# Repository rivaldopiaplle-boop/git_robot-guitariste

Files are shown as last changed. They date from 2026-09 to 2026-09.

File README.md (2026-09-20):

# Robot guitariste



Portfolio : https://git-portfolio-rivaldo.vercel.app/projets/robot-guitariste

Projet pluridisciplinaire d'équipe (ENIB, 4ᵉ année) : un robot qui se place sur les frettes d'une guitare et attaque la corde en rythme.

**Ma part** : modélisation des mécanismes et des chaînes cinématiques, outils de simulation en Python (trajectoires, vitesses, accélérations), analyse et optimisation des configurations, intégration mécanique / électronique / logiciel, documentation technique.

## Ce que contient le dossier

```
robot-guitariste/
├── firmware/
│   ├── control_guitarra/          micrologiciel STM32F411 (STM32CubeIDE), version de référence
│   └── versions-precedentes/      control_guitarra1, control_guitarra2
├── simulation/
│   ├── animation_cinematique.py   la cinématique du bras : modèle, trajectoires, animation
│   ├── produire-figures.py        rejoue la simulation et écrit les images, sans fenêtre
│   ├── sorties/                   les images produites, celles que montre le portfolio
│   └── essais/                    les scripts d'essai successifs, gardés pour mémoire
├── analyse-geste/
│   ├── analyser-kinovea.py        relit le relevé Kinovea et en tire les chiffres
│   └── sorties/                   le geste mesuré, sa vitesse, et mesures.json
├── cao-solidworks/                pièces, assemblages et animations SolidWorks
│   └── rendus/                    les animations converties, lisibles partout
├── documents/                     rapport signé, comptes rendus, planification, relevé Kinovea
│                                  (le logiciel Kinovea lui-même reste hors du dépôt)
└── archives/                      export d'origine du projet
```

## Le geste humain, mesuré avant d'être imité

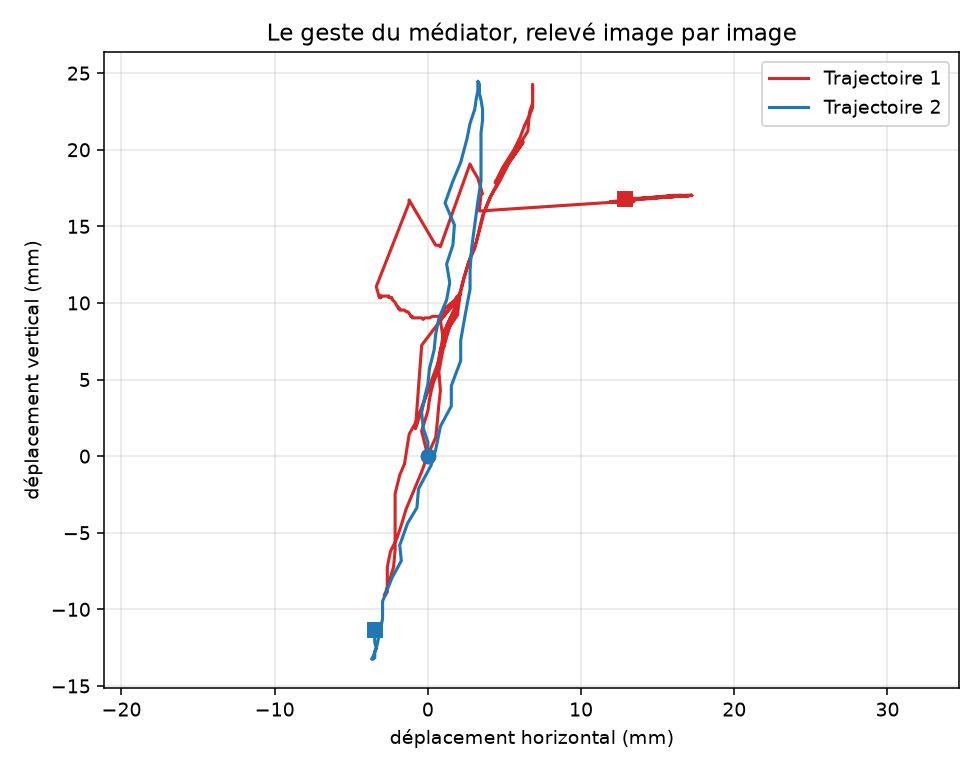
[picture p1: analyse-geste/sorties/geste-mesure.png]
Le geste du médiator relevé image par image


On ne dimensionne pas un robot guitariste sur une intuition. Le geste a d'abord été filmé
au ralenti, à cinquante images par seconde, puis suivi point par point dans Kinovea avec un
étalonnage pris sur l'écart entre deux cordes, onze millimètres. `analyse-geste/` relit ce
relevé et en tire les chiffres qui contraignent le mécanisme :

| Mesure | Valeur |
|---|---|
| Points suivis | 272 sur 5.42 s |
| Amplitude du balayage | 33.3 mm, soit environ trois cordes |
| Chemin parcouru par le médiator | 185.7 mm |
| Vitesse maximale | 465 mm/s |
| Vitesse moyenne | 34 mm/s |

C'est la cible. Les courbes de la simulation, plus bas, disent ce que le mécanisme sait
faire ; l'écart entre les deux est ce qui a guidé les choix de conception.

```bash
cd analyse-geste && python analyser-kinovea.py
```

## La simulation cinématique

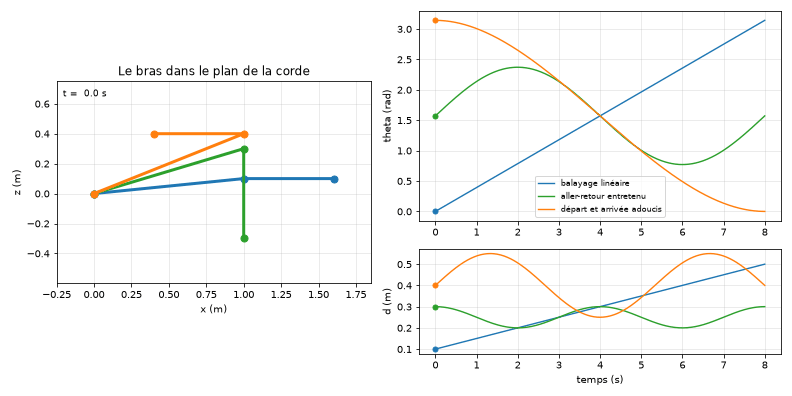
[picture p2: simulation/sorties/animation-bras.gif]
Le bras en mouvement


Le mécanisme compte deux axes : une articulation prismatique qui porte le bras le long de
la corde, et une articulation rotoïde qui présente l'outil sur la frette. La position de
l'outil se calcule directement, `x = A + B cos(theta)` et `z = d - B sin(theta)`, ce qui
permet d'éprouver un mouvement avant de l'usiner.

Trois mouvements sont éprouvés : un balayage linéaire, un aller-retour entretenu, et un
déplacement adouci au départ et à l'arrivée. Les courbes de vitesse et d'accélération
disent lequel le mécanisme peut suivre :

| Mouvement | Vitesse maximale | Accélération maximale |
|---|---|---|
| Balayage linéaire | 0,39 rad/s | 0 rad/s² (vitesse constante) |
| Aller-retour entretenu | 0,63 rad/s | 0,49 rad/s² |
| Départ et arrivée adoucis | 0,59 rad/s | 0,29 rad/s² |

Le troisième est le bon compromis : presque aussi rapide que l'aller-retour entretenu, avec
une accélération réduite de moitié, donc moins d'effort demandé au moteur et moins de
vibration transmise au manche.

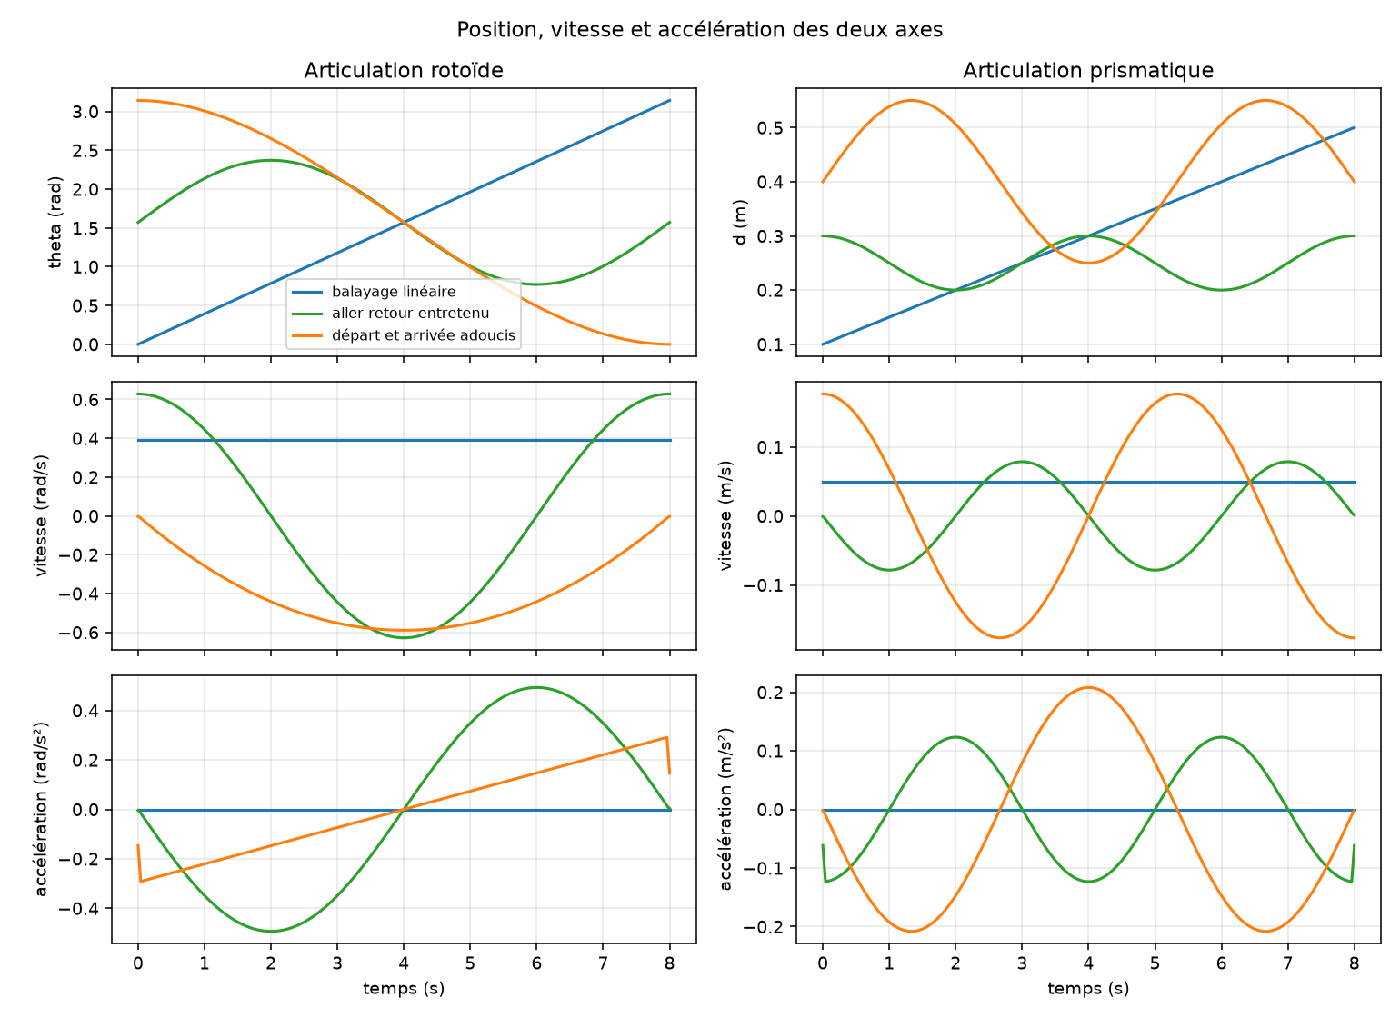
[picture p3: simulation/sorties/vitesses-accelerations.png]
Position, vitesse et accélération


## Reprendre le projet

| Partie | Outil | Démarrer |
|---|---|---|
| Micrologiciel | STM32CubeIDE, carte Nucleo STM32F411 | *File → Import → Existing Projects* → `firmware/control_guitarra`, puis *Build* et *Debug* |
| Interface de pilotage | Python 3 + `pyserial` | `python firmware/control_guitarra/hmi_guitarra.py` (port série de la carte) |
| Simulation | Python 3 + `numpy`, `matplotlib`, `pillow` | `cd simulation && python produire-figures.py` |
| Mécanique | SolidWorks | ouvrir `cao-solidworks/Assemblage1.SLDASM` |

Les vidéos (`documents/*.mp4`) restent sur la machine : elles dépassent la taille acceptée par GitHub.

## État

Terminé dans le cadre du projet d'école. Présenté dans le portfolio (fiche « Robot guitariste »).

## À améliorer

- [ ] Nettoyer `firmware/` : ne garder qu'une version, documenter les commandes série (codes `X1…X12`, états `EN`, `N`, `G`…)
- [ ] `requirements.txt` pour la simulation et l'interface
- [ ] Une vidéo courte du robot qui joue, hébergée hors du dépôt
- [ ] Schéma du câblage (moteur pas-à-pas, solénoïde, alimentation)

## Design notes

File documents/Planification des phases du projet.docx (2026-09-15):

Planification des phases du projet

Phase | Jour N° Semaine | Objectif Semaine | Lundi | Mardi | Mercredi | Jeudi | Vendredi | Samedi | Dimanche
Analyse & Préparation | 37 | - Tâches principales - Travail parallèle (multi-tâches) - Livrables / Objectifs | - Réunion de lancement avec encadrants (clarification objectifs, contraintes). - Étude du dispositif existant (robot-guitare précédent). - État de l’art : dispositifs d’excitation de corde (robots, médiators, autres systèmes). - Comparaison des approches mécaniques et robotiques. - Début de la recherche bibliographique sur les mouvements réels des guitaristes. - Classement des sources et articles scientifiques/vidéos. - Réorientation et clarification du travail à faire et Tableau comparatif des solutions existantes.
| 38 | | - Revue du cahier des charges. - Analyse des mouvements typiques d’un guitariste (angle, vitesse, flexibilité du médiator). - Définir les exigences dynamiques (trajectoire, force, fréquence). - Début modélisation cinématique d’un schéma simple (bras sériel ou parallèle 2 ddl). - Rapport État de l’art + analyse mouvements guitaristes
Modélisation & Dimensionnement | 39
| 40 | - Modélisation cinématique complète (bras sériel et parallèle, comparaison). - Simulation sous MATLAB/Simulink ou Python. - Étude des contraintes mécaniques (forces sur la corde, rigidité médiator). - Choix de l’architecture retenue (sériel ou parallèle).
Conception & Simulation | 41 | - Dimensionnement préliminaire (longueurs des bras, angles de travail, plage de mouvement). - Définir le nombre exact d’actionneurs et leurs caractéristiques. - Recherche de catalogues moteurs/servo + estimation coûts. - Schéma cinématique validé.
| 42 | - - Étude dynamique (vitesses, accélérations, couple moteur nécessaire). - Calculs de puissance et choix moteurs/servo. - En parallèle : début conception CAO (SolidWorks, CATIA, Fusion 360). - Fiche de choix des actionneurs.
Réalisation & Intégration partielle | 43 | - Conception CAO du dispositif (mécanisme complet avec médiator). - Vérification interférences, amplitude des mouvements. Préparation du plan de câblage électronique et schéma de commande. Maquette numérique CAO.
| 44 | - Validation CAO par simulation (trajectoire suivie, faisabilité). - Optimisation (ajustement longueurs, angles). Commande des composants mécaniques/électroniques nécessaires. Rapport conception + liste des pièces (BOM).
| 45 | - Réalisation prototype mécanique (impression 3D, découpe laser, assemblage). - Intégration médiator. Début programmation commande moteurs (Arduino, STM32, etc.). Prototype mécanique brut.
| 46 | - Intégration actionneurs (servo, moteurs). - Tests mécaniques sans guitare (trajectoire seule). Ajustement électronique (capteurs fin de course, réglages). Dispositif fonctionnel (phase 1).
| 47 | - Validation sur guitare (premiers tests de grattage). - Analyse du son produit (qualité excitation). Optimisation des paramètres (vitesse, trajectoire). Rapport tests intermédiaires.
| 48 | - Correction défauts (blocage, rigidité médiator). - Optimisation mécanique (renforts, flexibilité médiator). Rédaction rapport final (début). Version presque finale du dispositif.
Validation finale & Restitution | 49
| 50 | - Intégration finale au robot-guitare existant. - Tests complets sur mélodies programmées. - Présentation aux encadrants. Finalisation du rapport + diaporama soutenance. Rapport complet + démonstration finale
| 51

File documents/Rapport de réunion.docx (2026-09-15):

Rapport de réunion

Réalisation d’une trajectoire complexe pour médiator de robot-guitare

Date : Vendredi 12 septembre 2025, 14h00
Lieu : ENIB

Encadreurs :

M. Guillaume Helbert M. Olivier Chocron

# 1 Contexte du projet

Le projet s’inscrit dans la continuité d’un précédent PPE ayant conduit à la conception d’un premier prototype de robot-guitare capable de jouer une mélodie préprogrammée.
Le dispositif actuel utilise un médiator fixé à l’arbre d’un servo-moteur. Toutefois, la trajectoire simple et la rigidité du médiator entraînent plusieurs limitations :

- Risque de blocage mécanique,
- Dégradation de la qualité sonore,
- Réglage délicat de la position du médiator.

L’objectif de ce nouveau projet est de développer un dispositif plus performant permettant d’obtenir une trajectoire sophistiquée et fluide tout en limitant la complexité du robot-guitare. L’étude porte sur la conception et la modélisation d’un mécanisme sériel ou parallèle comportant au maximum deux actionneurs.

# 2 Ordre du jour de la réunion

- Réorientation du travail à réaliser,
- Présentation par les étudiants de leurs recherches,
- Discussion des solutions possibles pour l’excitation des cordes,
- Définition des tâches techniques à réaliser pour la prochaine échéance.

# 3 Travaux présentés par les étudiants

Les recherches ont été organisées autour de trois axes principaux :

## 3.1 Actionneur par corde

- Solutions étudiées :
  1. Utilisation d’électroaimants pour exciter directement les cordes (applicable uniquement aux guitares électriques, limitation importante).
  2. Utilisation de plusieurs servomoteurs, un par corde (problèmes identifiés : qualité du timbre non garantie, risque de blocage persistant).

## 3.2 Mouvement continu et fluide du médiator

- Étude de systèmes permettant un déplacement multidimensionnel du médiator.
- Solutions retenues :
  - Mécanismes 2D combinant rotation et translation,
  - Systèmes à double rotation ou inversion de mouvement.
- Décision : approfondir l’étude de ces mécanismes, jugés prometteurs pour assurer une attaque fluide des cordes.
- Apport des encadreurs :
  - Olivier Chocron a fourni des documents de référence,
  - Une séance technique est prévue le mardi 16 septembre à 14h00 pour détailler davantage ces mécanismes.

## 3.3 Bras robotique multi-degrés de liberté

- Solution étudiée mais jugée peu pertinente car nécessitant trois articulations.
- Limites : encombrement trop important, complexité inutile par rapport aux besoins du projet.

# 4 Travaux à réaliser (prochaines étapes)

- Étudier en détail les mécanismes 2D (rotation–translation, double rotation),
- Déterminer l’angle idéal d’attaque de la corde et la vitesse optimale du médiator,
- Préparer une restitution des résultats pour la prochaine réunion.

# 5 Conclusion

La réunion a permis de clarifier les orientations du projet et de cibler les solutions les plus pertinentes.
Les étudiants concentreront leurs efforts sur les mécanismes permettant un mouvement fluide et continu du médiator, avec pour objectif une amélioration notable de la qualité sonore et de la fiabilité du robot-guitare.

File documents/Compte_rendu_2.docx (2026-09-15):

Compte-rendu

Projet Robot-Guitare

Dates :

Mardi 17 septembre 2025, (séance de suivi) — ENIB

Participants :

- M.Olivier Chocron (encadrant)
- Deux étudiants (équipe projet)
- Invité : roboticien / guitariste

# 1 Observations et apports de l’invité

L’invité a permis de récolter une trajectoire expérimentale du médiator. L’analyse montre un mouvement composé principalement d’une translation associée à des rotations (variations d’angle) qui est un mouvement plus complexe que la simple rotation initiale.

# 2 Mouvements et solutions étudiées (retour synthétique)

Les solutions et configurations étudiées lors de la séance :

## 2.1 Double rotation (complexe)

  - Trajectoire complexe qui nécessité de modéliser la courbe des variations angulaires des deux rotoïdes ainsi que la précision des vitesses angulaires.
  - Considéré puissant mais difficile à maîtriser (contrôle / synchronisation).

## 2.2 Translation + rotation passive (médiator flexible)

  - Une translation primaire où la flexibilité du médiator permet une rotation passive pour franchir la corde.
  - Avantage : simplification mécanique si le médiator a suffisamment de flexibilité.

## 2.3 Translation + rotation de reconfiguration (rotation inchangée pendant l’attaque)

  - La rotation ne varie pas pendant le mouvement d’attaque, ici l’angle est reconfiguré après chaque demi-tour pour préparer la prochaine attaque.
  - Permet un contrôle simpler de l’attaque, mais nécessite une stratégie de reconfiguration fiable.

## 2.4 Translation + rotation active (servo)

  - Rotation commandée par servo si le médiator est peu flexible.
  - Avantage : contrôle précis de l’angle d’attaque ;
  - Inconvénient : nécessite un deuxième actionneur ou un servo plus complexe.

# 3 Apports pédagogiques et techniques (M. Chocron)

- M. Chocron a donné un cours sur l’étude des mouvements et la détermination de la trajectoire théorique du médiator.
- Exercice demandé : application et compréhension de la matrice DH (Denavit–Hartenberg) pour modéliser la cinématique du mécanisme.

# 4 Décisions et orientations

- Poursuivre le travail autour des mécanismes 2D (translation + rotation en diverses configuations).
- Évaluer en priorité les solutions 2, 3 et 4 (cf. section mouvements) en parallèle :
  - Tester la solution passive si le médiator est suffisamment flexible.
  - Préparer une version avec rotation active si la flexibilité ne suffit pas.
- Utiliser DH + MATLAB pour modéliser et Kinovea pour valider expérimentalement.

# 5 Points ouverts / Propositions pour la suite

- Évaluer les contraintes sonores (qualité du timbre) lors des premiers essais et ajuster la géométrie du médiator.
- Penser à une stratégie de commande / synchronisation des actionneurs si une solution à deux actionneurs est retenue.

# Conclusion :

La séance du 17 septembre a permis d’affiner les orientations techniques et d’obtenir une trajectoire réelle utile pour la modélisation. Les prochaines étapes consistent à produire les livrables et à se réunir pour comparer théorie et expérience.

Rédigé par : équipe projet — ENIB

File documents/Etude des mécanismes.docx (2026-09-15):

# 1 Etude des mécanismes

## 1.1 Schéma cinématique

Figure 1schema cinematique

## 1.2 Simple translation

Temps

ϴ

Motif

## 1.3 Système de translation et rotation de configuration

motif

ϴ

Temps

# 2 Etude des trajectoires

## 2.1 Système devoir

## 2.2 Système reel

## 2.3 Kinovea

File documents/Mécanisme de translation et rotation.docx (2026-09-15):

1. Mecanisme de rotation et translation
  a) Schéma cinématique
  b) Trajectoire
  c) D
2. Mecanisme double rotation
  a) Schéma cinématique
  b) Trajectoire
  c) ngle

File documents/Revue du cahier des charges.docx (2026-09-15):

Revue du cahier des charges

1. Diagramme bête à corne

Produit Système de Grattage
Sur quoi le produit agit-il?
Corde
A qui le produit rend t-il service?
Guitare incomplette
Dans quel but?
Joue la guitare sans blocage du Mediator

2. Diagramme pieuvre

Système de Grattage
Corde
Guitare
Microcontroleur

Fonction de service | Descrption
FP | Joue la guitare sans blocage du Mediator sur la corde
FC1
FC2
FC3

Fonction de service | Critere | Niveau | Flexibilité
FP | Angle
| Vitesse
| Flexibilité du Mediator
FC1
FC2
FC3

3. Diagramme FAST
4. Diagramme SADT

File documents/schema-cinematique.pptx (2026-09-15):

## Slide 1

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
La corde

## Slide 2

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
La corde

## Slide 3

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
La corde

Z0

Y0

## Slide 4

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
CORDE

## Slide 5

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
La corde

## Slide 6

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
La corde

X0

Z0

Y0

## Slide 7

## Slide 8

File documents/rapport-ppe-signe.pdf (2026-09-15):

Rapport Technique PPE – Projet Pluridisciplinaire

ENIB Ű Année 2025

# Réalisation dŠune trajectoire complexe pour médiator de robot-guitare

Réalisé par les étudiants :

Piaplle Simo FRand Rivaldo | Yassine Khodor

Projet réalisé sous la supervision de :

Guillaume Helbert | Olivier Chocron

### 19 décembre 2025

Composition du jury

# Composition du jury

Ce travail a été présenté et évalué devant un jury composé de :

Encadrants : M. CHOCRON Olivier

M. HELBERT Guillaume

Assesseur : M. DELALEAU Emmanuel

i

Dédicaces

# Dédicaces

À nos familles et enseignants.

ii

Remerciements

# Remerciements

Nous tenons à exprimer notre sincère gratitude à lŠÉcole Nationale dŠIngénieurs de Brest (ENIB) pour nous avoir offert lŠopportunité de réaliser ce projet, qui a constitué une expérience formatrice aussi bien sur le plan technique quŠhumain.
Nous adressons nos remerciements les plus respectueux à M. Guillaume Helbert et M. Olivier Chocron, encadreurs de ce projet, pour la conception du sujet, la qualité de leur accompagnement, leurs conseils avisés et leur disponibilité tout au long de ce travail. Leur encadrement rigoureux et bienveillant a été déterminant dans la réussite de ce projet. Nous remercions également M. Éric Boucharie pour son aide précieuse, son implication et son soutien technique constant, qui ont grandement contribué à lŠavancement et à lŠaboutissement de nos travaux.
EnĄn, nous souhaitons remercier nos familles et amis pour leur soutien moral, leurs encouragements et leur compréhension tout au long de la réalisation de ce projet

iii

Résumé

# Résumé

Ce projet sŠinscrit dans le cadre dŠun Projet Pluri-disciplinaire dŠÉtudes (PPE) visant à améliorer le fonctionnement dŠun robot-guitare capable de jouer automatiquement des morceaux de musique préprogrammés. Lors dŠun travail précédent, un système monocorde avait été développé avec succès pour la variation de la longueur vibrante de la corde à lŠaide dŠun solénoïde, permettant ainsi de jouer différentes notes sans difficulté majeure. Cependant, un problème critique subsistait au niveau de lŠexcitation de la corde. Le médiator, Ąxé directement sur lŠarbre dŠun servomoteur, attaquait la corde de manière essentiellement perpendiculaire. Cette trajectoire extrêmement simple, combinée à la rigidité du médiator, provoquait de fréquents blocages mécaniques, une dégradation de la qualité sonore et rendait le réglage de la position du médiator particulièrement délicat. LŠobjectif principal de ce projet a donc été de concevoir un nouveau système dŠexcitation de la corde capable de suivre une trajectoire plus élaborée, inspirée du geste réel dŠun guitariste, tout en conservant une architecture mécanique simple. Pour répondre à cette problématique, un mécanisme à deux degrés de liberté a été proposé, combinant une translation linéaire et une rotation du médiator.
La démarche suivie repose sur une analyse du geste musical réel, lŠétude de lŠexistant, une modélisation cinématique à lŠaide de la méthode de DenavitŰHartenberg, puis une simulation numérique en Python aĄn de valider la faisabilité et la pertinence de la trajectoire obtenue. Ce travail pose ainsi les bases dŠun système plus Ąable, évolutif et mieux adapté à un jeu guitaristique réaliste.

iv

Présentation du cadre du PPE

# Présentation du cadre du PPE

## Présentation générale

Le Projet Professionnalisant en Équipe (PPE) se déroule dans le cadre pédagogique de lŠÉcole Nationale dŠIngénieurs de Brest (ENIB), et vise à immerger les étudiants dans une situation proche de celle rencontrée en entreprise. Ce projet est encadré par des enseignants-chercheurs jouant le rôle de responsables techniques et de clients, aĄn de reproduire les exigences et contraintes réelles dŠun environnement professionnel.

## Secteur et activité

Le projet sŠinscrit dans le domaine de la mécatronique et de la robotique appliquée, combinant plusieurs disciplines :
⋆ conception mécanique et modélisation ;
⋆ électronique embarquée et capteurs ;
⋆ informatique et automatisation ;
⋆ simulation et validation expérimentale.

## Organisation et fonctionnement

LŠéquipe fonctionne comme un véritable bureau dŠétudes : répartition claire des rôles, réunions de suivi régulières, livrables intermédiaires et planiĄcation des étapes. Chaque membre est responsable de sa partie tout en participant à lŠintégration globale du système.

v

Table des matières | Table des matières

# Table des matières

Composition du jury | i
Dédicaces | ii
Remerciements | iii
Résumé | iv
Présentation du cadre du PPE | v
Introduction | 1
1 État de lŠart | 3

### 1.2.1 Bras robotisé industriel pour lŠexécution automatisée de la guitare

### 1.2.3 Architecture à glissières motorisées pour le jeu robotisé multi-cordes 5

1.3.1 Sélection de la technique de jeu à robotiser : le Sweep Picking . . . | 6
2 Étude et conception du système de grattage | 8

vi

Table des matières | Table des matières

### 2.3.1 Détermination de la trajectoire par analyse vidéo (Kinovea) . . . . 14

3 Réalisation et intégration du système | 17

### 3.4.5 Interface utilisateur graphique et ajout de la commande du médiator 23

4 Compétences et responsabilité professionnelle | 24
Conclusion | 27
Bibliographie | I
Annexes | I

vii

Table des matières | Table des matières
A Mises en plan des pièces imprimées en 3D | II

viii

Table des Ągures | Table des Ągures

# Table des Ągures

### 2.1 Comparaison entre le modèle géométrique étendu (3 DDL) et le modèle

### 2.2 Comparaison entre le modèle étendu et le modèle réel du mécanisme à

### 2.5 Simulation Python de la trajectoire du médiator à partir des paramètres

### 3.1 Présentation des pièces mécaniques principales du système de commande

### 3.2 Vue dŠensemble de lŠassemblage mécanique avec indication des principaux

A.1 Plan du chariot linéaire | III
A.2 Plan du support moteur pas à pas | IV
A.3 Plan du support de lŠaxe secondaire | V
A.4 Plan du système tendeur de courroie | VI
A.5 Plan de lŠécrou tendeur de courroie | VII
A.6 Plan du médiator imprimé | VIII

ix

Liste des tableaux | Liste des tableaux

# Liste des tableaux

### 1.1 Comparaison des principales architectures robotiques dédiées au jeu de la

guitare | 6

2.1 Paramètres DH modiĄés du mécanisme translationŰrotation | 10 2.2 Matrice homogène Ąnale 0T du mécanisme translationŰrotation | 10 2.3 Paramètres DH modiĄés du mécanisme double rotation | 11 2.4 Matrice homogène Ąnale 0T du mécanisme double rotation | 11 2.5 Comparaison des mécanismes translationŰrotation et double rotation . . . 12 2.6 Synthèse des modèles DH modiĄés | 14

x

Liste des équations | Liste des équations

# Liste des équations

### 2.3 Position du médiator du mécanisme translation rotaion avec angle passif . . . . 13

xi

Introduction

# Introduction

## Contexte général du projet

La robotisation du geste musical constitue aujourdŠhui un domaine de recherche et dŠexpérimentation à la croisée de la mécatronique, de la robotique et de lŠart. Dans ce contexte, lŠENIB a lancé un nouveau projet pédagogique ambitieux : la conception dŠune guitare capable de jouer de manière autonome des morceaux musicaux préprogrammés. Ce robot-guitare repose sur plusieurs sous-systèmes : la variation de la longueur vibrante de la corde pour produire différentes notes, le contrôle du rythme, ainsi que lŠexcitation de la corde permettant de générer le son. Si les premiers travaux ont permis de valider certaines briques fonctionnelles, notamment la gestion des notes via un solénoïde, la partie liée au grattage de la corde reste aujourdŠhui le principal verrou technologique. Le geste du guitariste est en réalité complexe et Ąnement contrôlé. Il ne sŠagit pas simplement de frapper une corde, mais de suivre une trajectoire précise, avec un angle dŠattaque adapté, une vitesse maîtrisée et une interaction progressive avec la corde. Reproduire ce geste de manière robotisée représente un déĄ majeur, tant sur le plan mécanique que sur le plan de la modélisation et de la commande.

## Contexte professionnel du PPE

Ce projet sŠinscrit dans un PPE de niveau ingénieur, ayant pour objectif de placer lŠétudiant dans une situation proche de celle rencontrée en entreprise. LŠétudiant doit analyser un besoin réel, proposer des solutions techniques, les justiĄer et les valider par simulation et expérimentation, tout en respectant les contraintes du projet.

## Problématique

Le système dŠexcitation développé lors du projet précédent repose sur un médiator rigide monté directement sur lŠarbre dŠun servomoteur. Cette conĄguration impose une trajectoire très simpliĄée, essentiellement perpendiculaire à la corde. Or, ce type dŠattaque ne correspond pas au geste réel dŠun guitariste et engendre plusieurs problèmes :

1

Introduction

- un risque élevé de blocage mécanique du médiator contre la corde ;
- une dégradation de la qualité sonore produite ;
- une usure prématurée des composants ;
- une impossibilité de reproduire des techniques de jeu réalistes (sweep picking, strumming, etc.).
Cette problématique correspond à un verrou technologique réel dans le domaine de la robotique musicale, où la reproduction Ądèle des gestes humains constitue une difficulté majeure à la fois mécanique, cinématique et acoustique. Le projet vise donc à concevoir une solution Ąable et reproductible tout en intégrant des contraintes de performance et de durabilité.
La problématique centrale de ce projet peut donc être formulée comme suit : comment

concevoir un mécanisme simple, robuste et réglable, capable de reproduire une trajectoire de grattage réaliste du médiator, tout en limitant le nombre d’actionneurs et la complexité du système ?

## Objectifs du projet

Objectif principal :
⋆ Concevoir et valider un système dŠexcitation de corde basé sur une trajectoire complexe du médiator, inspirée du geste réel dŠun guitariste.
Objectifs secondaires :
→ Étudier les techniques de jeu à la guitare et les mécanismes robotiques existants ; → Modéliser le mécanisme retenu à lŠaide de la méthode de DenavitŰHartenberg ; → Simuler numériquement le mouvement du médiator en Python ;
→ Dimensionner mécaniquement le système ;
→ Préparer lŠintégration future dans un robot-guitare multi-cordes.

2

État de lŠart

# Chapitre 1

# État de lŠart

Cette section vise à analyser les principales solutions robotiques développées pour le jeu automatisé de la guitare. LŠétude de ces systèmes permet dŠidentiĄer les choix technologiques dominants, ainsi que leurs limites mécaniques et fonctionnelles, aĄn de positionner clairement lŠapproche retenue dans ce projet.

## 1.1 Les rythmes et techniques de jeu à la guitare

Le jeu au médiator comporte plusieurs techniques permettant de produire des effets sonores, des rythmes et des motifs mélodiques variés. Parmi les méthodes les plus utilisées, on distingue les techniques suivantes.

### 1.1.1 Alternate Picking

Technique consistant à jouer les cordes avec un mouvement régulier basŰhaut du médiator. La main droite exécute un aller-retour continu, garantissant un rythme stable, tandis que la main gauche change les notes sur le manche. Cette méthode permet de jouer des lignes rapides et Ćuides ainsi que des transitions efficaces entre les cordes.

### 1.1.2 Cross Picking

Technique fondée sur un mouvement roulé et rythmique sur deux à trois cordes, alternant précisément les coups de médiator. Elle produit un effet arpégique dynamique et régulier, enrichissant lŠaccompagnement musical et apportant Ćuidité et mouvement à la mélodie.

### 1.1.3 Sweep Picking

Technique consistant à balayer plusieurs cordes dŠun seul mouvement Ćuide du médiator. La main droite effectue un balayage continu, tandis que la main gauche

3

État de lŠart | Systèmes robotiques existants pour le jeu de la guitare

enchaîne les notes sur le manche pour former des arpèges rapides. Cette méthode permet dŠobtenir des motifs très rapides et expressifs tout en conservant un mouvement simple et contrôlé.

### 1.1.4 Tremolo Picking

Technique où le médiator réalise des allers-retours très rapides sur une seule corde. La main droite fournit lŠessentiel du travail en répétant intensément la même note, produisant un effet de trémolo ou de vibration sonore typique. Cela permet de maintenir une note ou un motif avec une très grande amplitude rythmique.
Contraintes musicales : angle du médiator, vitesse, profondeur dŠattaque, régularité du geste.

## 1.2 Systèmes robotiques existants pour le jeu de la guitare

### 1.2.1 Bras robotisé industriel pour lŠexécution automatisée de

la guitare acoustique

Ce système utilise un bras robotisé industriel couplé à un mécanisme dédié Ąxé sur la table dŠharmonie de la guitare. Le bras positionne et oriente lŠactionneur, tandis quŠun ensemble de moteurs linéaires et rotatifs assure le déplacement devant les cordes, le grattage et le contrôle de la position longitudinale sur le manche.

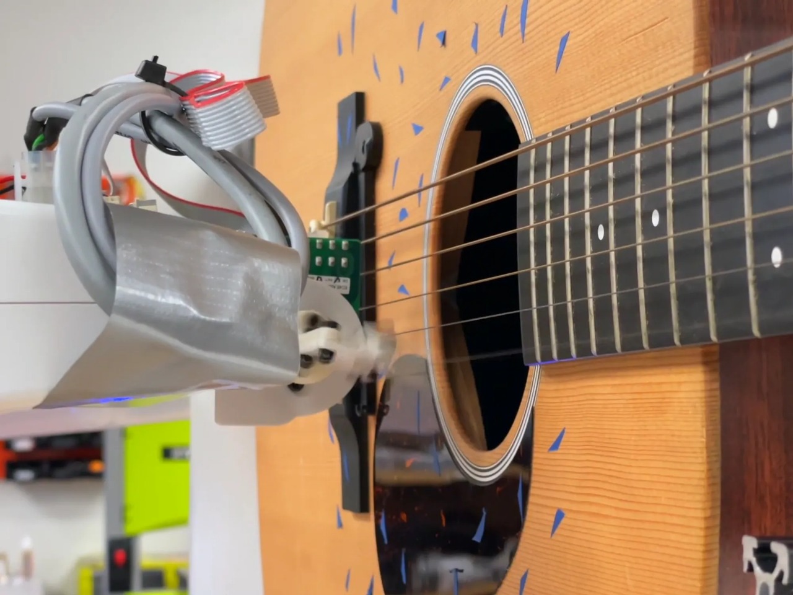
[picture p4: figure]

Figure 1.1 Ű Robot à bras industriel jouant une guitare acoustique.

4

État de lŠart | Systèmes robotiques existants pour le jeu de la guitare

### 1.2.2 Mini-bras robotisé embarqué sur la structure de la guitare

Dans ce prototype, un petit bras robotisé à plusieurs degrés de liberté est directement Ąxé sur la caisse de la guitare. Il tient un médiator en bout dŠoutil et réalise des mouvements rapides au voisinage de la rosace pour gratter les cordes selon des motifs programmés, en reproduisant des gestes de picking ou de strumming.

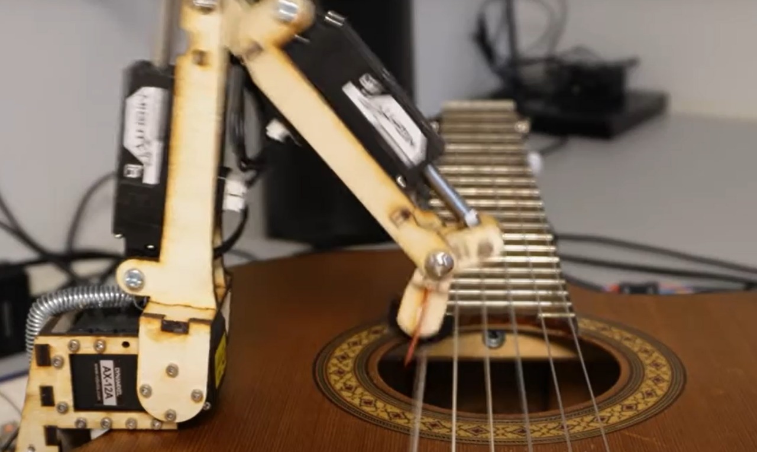
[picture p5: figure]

Figure 1.2 Ű Mini-bras robotisé Ąxé sur la caisse de la guitare.

### 1.2.3 Architecture à glissières motorisées pour le jeu robotisé

multi-cordes

Ce mécanisme repose sur plusieurs glissières linéaires empilées, chacune associée à une corde. Sur chaque axe, un chariot motorisé porte un actionneur (médiator ou percuteur) qui se déplace le long de la corde et peut être commandé individuellement. LŠensemble forme un système multi-voies capable de jouer plusieurs lignes musicales en parallèle.

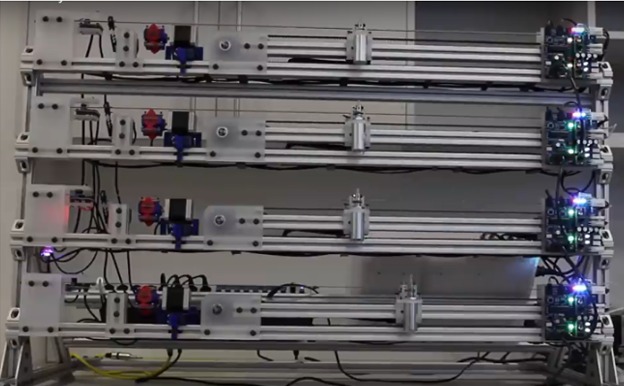
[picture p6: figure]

Figure 1.3 Ű Système de glissières motorisées pour plusieurs cordes.

5

État de lŠart | DéĄnition du besoin et choix de lŠapproche retenue

### 1.2.4 Synthèse comparativee

LŠanalyse des systèmes existants met en évidence un compromis fondamental entre réalisme du geste guitaristique, complexité mécanique et évolutivité du système. Les bras robotisés industriels permettent de reproduire des trajectoires complexes, mais au prix dŠun surdimensionnement important. Les mini-bras embarqués réduisent lŠencombrement, tout en conservant une cinématique riche, mais restent difficiles à simpliĄer. EnĄn, les architectures à glissières motorisées offrent une bonne évolutivité multi-cordes, au détriment du réalisme du geste de grattage.

Table 1.1 Ű Comparaison des principales architectures robotiques dédiées au jeu de la guitare

Architecture | Complexité | Encombrement | Réalisme du geste | Évolutivité
Bras robotisé industriel Mini-bras embarqué Glissières multi-cordes | Élevée Moyenne Élevée | Élevé Faible Moyen | Élevé Moyen à élevé Moyen | Faible Moyenne Élevée

Au regard de cette comparaison, aucune des solutions existantes ne répond pleinement aux contraintes du projet PPE. Une architecture intermédiaire, reposant sur un nombre réduit de degrés de liberté mais capable de générer une trajectoire de grattage réaliste, apparaît comme un compromis pertinent. Ce constat motive le choix dŠun mécanisme à deux degrés de liberté, combinant translation et rotation du médiator.

## 1.3 DéĄnition du besoin et choix de lŠapproche retenue

### 1.3.1 Sélection de la technique de jeu à robotiser : le Sweep

Picking

Le sweep picking a été choisi comme première technique à robotiser car il constitue un compromis idéal entre simplicité mécanique et richesse du mouvement. LŠobjectif général du projet est de déĄnir et de maîtriser une trajectoire de grattage reproductible, pouvant ensuite être étendue à plusieurs cordes dans les versions futures du système. Le sweep picking repose précisément sur un mouvement dŠallerŰretour continu du médiator, suivant un angle de grattage bien déĄni, ce qui facilite sa modélisation cinématique et sa mise en œuvre dans un mécanisme robotisé. De plus, cette technique offre une base solide pour les étudiants futurs : lŠajout de cordes supplémentaires ou lŠextension du mécanisme à un balayage multi-cordes reste cohérent avec la même logique de mouvement. Ainsi, le sweep

6

État de lŠart | DéĄnition du besoin et choix de lŠapproche retenue

picking permet de développer un mécanisme simple au départ, mais évolutif, capable de servir de fondation à un système plus complet de jeu robotisé de la guitare.

### 1.3.2 Choix et justiĄcation du mécanisme cinématique retenu

Le mouvement à reproduire dans ce projet est un mouvement dŠallerŰretour simple, caractéristique du sweep picking. Cette technique impose deux exigences mécaniques principales : dŠune part, une translation permettant de se déplacer devant les cordes, et dŠautre part, un angle de grattage précis, mais ajustable, aĄn dŠobtenir un contact optimal avec la corde.
Le mécanisme retenu combine une translation linéaire avec une rotation du médiator autour dŠun axe Ąxe. Le bras robotisé se déplace selon une trajectoire rectiligne, frappe la corde avec un angle prédéĄni, puis effectue un mouvement symétrique lors du retour. Ce principe offre une cinématique simple, contrôlable, et facilement extensible aux cordes voisines dans une future version multi-cordes.
Ce mécanisme permet ainsi dŠobtenir un mouvement compatible avec le sweep picking et constitue une base Ąable et évolutive pour les travaux des futurs étudiants.

7

Étude et conception du système de grattage

# Chapitre 2

# Étude et conception du système de grattage

## 2.1 Analyse du dispositif issu des travaux précédents

Le projet réalisé par les étudiants précédents reposait sur un système monocorde utilisant trois actionneurs principaux : un moteur pas-à-pas pour déplacer un chariot le long de la corde, un solénoïde pour presser la corde contre une frette virtuelle, et un servomoteur S3003 Ąxe qui mettait la corde en vibration à lŠaide dŠun médiator. Le servomoteur était immobile dans lŠespace et effectuait uniquement un petit mouvement angulaire local, toujours au même endroit, pour frapper la corde.

Cette architecture permettait de jouer des notes successives en ajustant la longueur vibrante de la corde, mais présentait une limitation majeure : le mécanisme dŠexcitation était entièrement Ąxe. Le servomoteur ne pouvait agir quŠau même point et uniquement sur une seule corde, ce qui rendait impossible tout geste impliquant plusieurs cordes (sweep picking, strumming, cross picking, etc.). Le système ne pouvait donc pas reproduire des techniques réelles du jeu guitaristique.

Pour ces raisons, notre équipe doit remplacer ce mécanisme Ąxe par une solution plus performante : un actionneur mobile capable de se déplacer transversalement devant plusieurs cordes aĄn de réaliser des balayages, attaques successives et mouvements multi-cordes. Ce changement est indispensable pour dépasser les limites du prototype précédent et permettre un jeu plus proche dŠune guitare réelle.

De plus, il a été observé que le médiator se bloquait fréquemment lors du fonctionnement, ce qui provoquait des arrêts intempestifs et limitait fortement la Ąabilité du système. .

8

Étude et conception du système de grattage Modélisation théorique des mécanismes

## 2.2 Modélisation théorique des mécanismes

### 2.2.1 Objectif et contexte de la modélisation

Cette section présente la modélisation géométrique des deux architectures mécaniques envisagées pour le robot-guitare, dans le but dŠétudier et de comparer leur cinématique. La méthode retenue est celle de DenavitŰHartenberg modiĄée (DH modiĄé), couramment utilisée pour décrire la géométrie des chaînes cinématiques robotisées.
Les deux systèmes étudiés sont :
⋆ un mécanisme combinant un mouvement de translation linéaire et une rotation
(appelé ci-après mécanisme translation–rotation) ;
⋆ un mécanisme constitué de deux articulations rotatives successives (appelé ci-après
mécanisme double rotation).
LŠobjectif est de fournir une modélisation claire et rigoureuse de ces deux architectures, aĄn de justiĄer le choix Ąnal retenu pour le robot-guitare, tant du point de vue géométrique que mécanique et pratique.

### 2.2.2 Description des modèles DH modiĄés

Modèle DH du mécanisme translationŰrotation

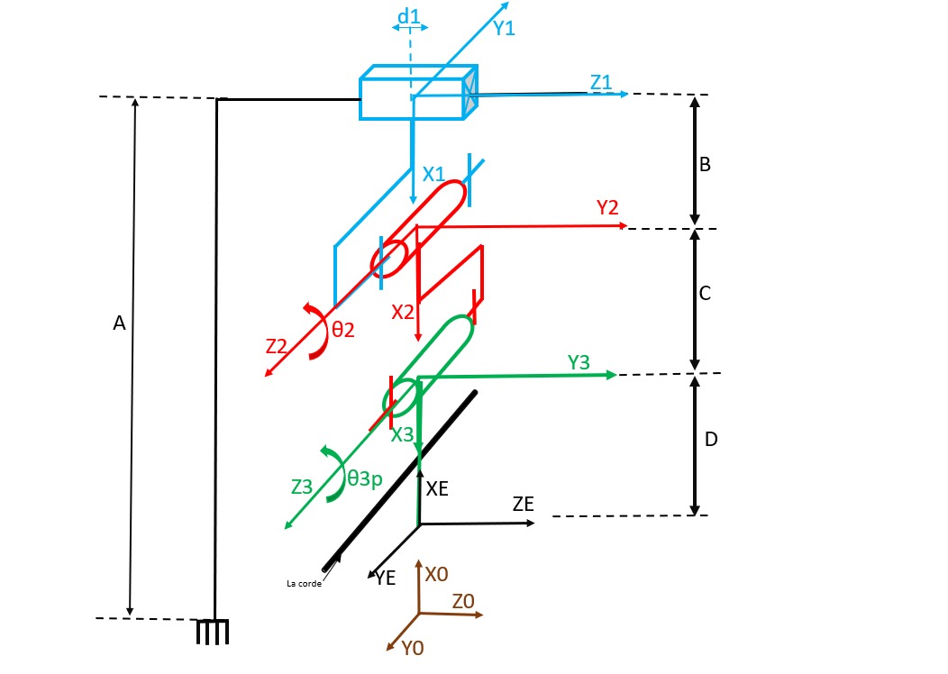
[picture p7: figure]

(a) Mécanisme translation–rotation à 3 degrés de liberté.

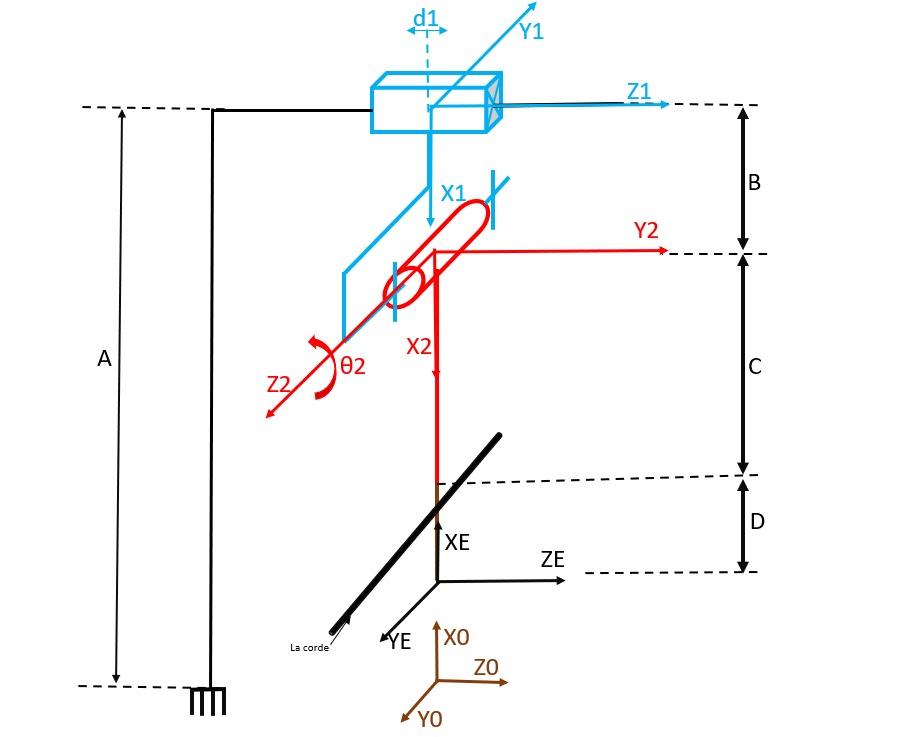
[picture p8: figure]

(b) Mécanisme translation–rotation à 2 degrés de liberté.
Figure 2.1 Ű Comparaison entre le modèle géométrique étendu (3 DDL) et le modèle réel (2 DDL).

Le mécanisme translation–rotation possède deux degrés de liberté actifs :
- une translation prismatique d1 correspondant au déplacement du chariot sur la glissière horizontale ;
- une rotation θ2 du bras supportant le médiator.

9

Étude et conception du système de grattage Modélisation théorique des mécanismes

Le tableau 2.1 présente les paramètres DH modiĄés associés à ce mécanisme.

Table 2.1 Ű Paramètres DH modiĄés du mécanisme translationŰrotation

i | αi | ai | di | θi
1 2 3 | 0 π/2 π/2 | A B C + D | d1 0 0 | π θ2 π

La matrice homogène Ąnale exprimant la position et lŠorientation du médiator dans le repère de base est donnée dans le tableau 2.2.

Table 2.2 Ű Matrice homogène Ąnale 0T du mécanisme translationŰrotation

0T =

cos θ2 | 0 sin θ2 | A − B − (C + D) cos θ2
0 | 1 | 0 | 0
− sin θ2 | 0 cos θ2 | d1 + (C + D) sin θ2
0 | 0 | 0 | 1

La position du médiator est donc donnée par lŠéquation (2.1) :

xE = A − B − (C + D) cos θ2,

zE = d1 + (C + D) sin θ2.

(2.1)

Cette modélisation met en évidence une cinématique pratiquement découplée entre la translation d1 et la rotation θ2, ce qui facilite grandement la commande et la planiĄcation des trajectoires.

10

Étude et conception du système de grattage Modélisation théorique des mécanismes

### 2.2.3 Modèle DH du mécanisme double rotation

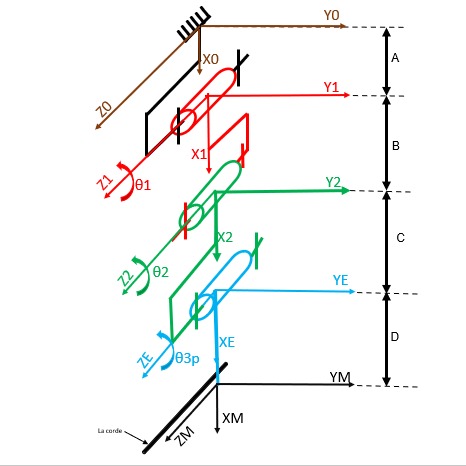
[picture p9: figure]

(a) Mécanisme à double rotation – modèle géométrique étendu (3 degrés de liberté).
(b) Mécanisme à double rotation – modèle géométrique réel (2 degrés de liberté).
Figure 2.2 Ű Comparaison entre le modèle étendu et le modèle réel du mécanisme à double rotation.

Le mécanisme dit double rotation comporte deux degrés de liberté actifs, correspondant aux angles de rotation θ1 et θ2 des deux articulations successives.
Le tableau 2.3 présente ses paramètres DH modiĄés.

Table 2.3 Ű Paramètres DH modiĄés du mécanisme double rotation

i | αi | ai | di | θi
1 2 3 | 0 0 0 | A B C + D | 0 0 0 | θ1 θ2 0

La matrice homogène Ąnale est donnée au tableau 2.4 :

Table 2.4 Ű Matrice homogène Ąnale 0T du mécanisme double rotation

0T =

cos(θ1 + θ2) − sin(θ1 + θ2) 0 A + B cos θ1 + (C + D) cos(θ1 + θ2)
sin(θ1 + θ2) | cos(θ1 + θ2) | 0 | B sin θ1 + (C + D) sin(θ1 + θ2)
0 | 0 | 1 | 0
0 | 0 | 0 | 1

La position du médiator dans le plan (x, y) est donnée par lŠéquation (2.2) :

11

Étude et conception du système de grattage Modélisation théorique des mécanismes

xM = A + B cos θ1 + (C + D) cos(θ1 + θ2),

yM = B sin θ1 + (C + D) sin(θ1 + θ2).

| (2.2)

La présence dŠun couplage trigonométrique fort entre les deux angles actifs rend la résolution géométrique directe et inverse plus complexe et augmente la sensibilité aux singularités mécaniques.

### 2.2.4 Analyse comparative des deux mécanismes

Le tableau 2.5 synthétise la comparaison des deux architectures selon différents critères dŠanalyse.

Table 2.5 Ű Comparaison des mécanismes translationŰrotation et double rotation

Critère dŠévaluation | Mécanisme transla-tionŰrotation | Mécanisme double rota-tion
Structure mécanique | Rail robuste et stable assu-rant un guidage linéaire précis ; faibles moments mécaniques. | Structure en porte-à-faux avec bras articulés ; moments im-portants et sollicitations plus élevées.
Complexité cinématique | Modèle pratiquement découplé avec une cinématique simple facilitant la commande et la modélisation. | Couplage trigonométrique fort entre les articulations, géné-rant des solutions multiples et sensibilité aux singularités.
Encombrement et intégra-tion | Volume dŠexclusion faible, montage compact aligné avec la guitare, facilité dŠintégra-tion. | Encombrement plus important du fait des rotations succes-sives, avec espace requis pour la libre rotation.
Montage et câblage | Montage simple (rail + bras) avec câblage aisé. | Montage plus complexe avec câblage et passages de câbles plus délicats.
Robustesse et maintenance | Robustesse accrue due à la ré-partition des efforts sur le rail, maintenance facilitée. | Sensibilité accrue aux jeux et aux Ćexions des articulations, maintenance plus complexe.
Précision et répétabilité | Précision élevée garantie par la commande découplée et la rigi-dité mécanique. | Précision impactée par le cou-plage et les phénomènes méca-niques non linéaires.

12

Étude et conception du système de grattage Modélisation théorique des mécanismes

### 2.2.5 JustiĄcation du choix du mécanisme translationŰrotation

Le choix du mécanisme combinant un mouvement de translation linéaire et une rotation sŠappuie sur plusieurs arguments techniques et pratiques essentiels :

- Cinématique simple et robuste : La modélisation DH révèle une structure presque découplée, ce qui permet une commande plus directe et Ąable, réduisant les risques dŠerreurs et de singularités.
- Intégration mécanique facilitée : Le montage sur rail linéaire garantit un guidage précis et stable, avec un encombrement réduit compatible avec la forme de la guitare et un impact minimal sur la manipulation de lŠinstrument.
- Réduction des efforts et moments mécaniques : La répartition des charges sur le rail limite les sollicitations sur les articulations, augmentant la durée de vie des composants et la précision du positionnement.
- Simplicité de maintenance : La structure plus simple réduit les risques de dysfonctionnement et facilite les opérations de maintenance et de réglage.
- Simulation et génération de trajectoires : LŠintroduction dŠun troisième degré de liberté passif virtuel (θ3p

), uniquement pour la simulation, permet dŠenrichir la modélisation sans complexiĄer la mécanique réelle (voir section 2.2.6).

LŠensemble de ces éléments justiĄe pleinement le recours au mécanisme translationŰrotation pour le robot-guitare, conformément aux objectifs de performance, dŠintégration et de Ąabilité.

### 2.2.6 Introduction du degré de liberté passif pour la simulation

AĄn dŠaméliorer la modélisation de lŠorientation du médiator lors du contact avec la corde, un troisième angle θ3p

est introduit comme degré de liberté passif dans la simulation.
Ce degré de liberté ne correspond pas à un actionneur réel, mais permet dŠajuster virtuellement lŠorientation du médiator pour générer des trajectoires plus réalistes de
sweep picking.
La position Ąnale du médiator dans le plan (x, z) est alors décrite par lŠéquation (2.3) :

xE = A − B − C cos θ2 − D cos(θ2 + θ3p
| ),

zE = d1 + C sin θ2 + D sin(θ2 + θ3p

| ). (2.3)

Cette extension du modèle permet de concilier simplicité mécanique et réalisme cinématique dans la simulation numérique, sans augmenter la complexité physique du système.

13

Étude et conception du système de grattage | Conception du dispositif

### 2.2.7 Résumé des modèles étudiés

Le tableau 2.6 résume les caractéristiques principales des modèles DH considérés.
Table 2.6 Ű Synthèse des modèles DH modiĄés
Modèle | Degrés de liberté | Rôle | Usage principal
Mécanisme réel | d1, θ2 (2 actifs) | Description physique et commande | Dimensionnemen
Modèle étendu | d1, θ2 (actifs) + θ3p
| (passif) | Simulation enrichie | Génération de tra

## 2.3 Conception du dispositif

### 2.3.1 Détermination de la trajectoire par analyse vidéo (Kino-

vea)

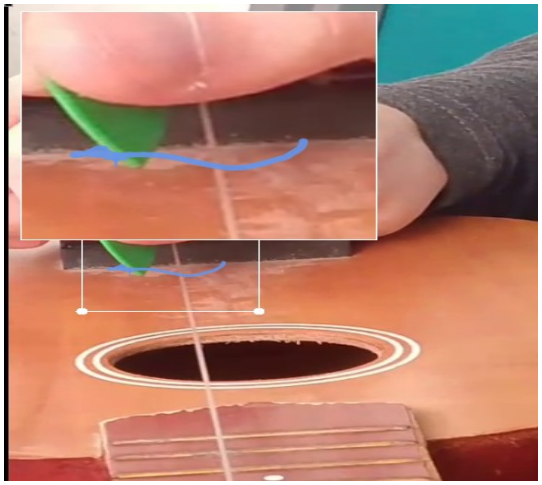
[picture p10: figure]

Figure 2.3 Ű trajectoire du mediator.

La trajectoire du médiator a été déterminée à partir dŠune analyse vidéo réalisée avec le logiciel Kinovea. Cette méthode permet dŠextraire précisément les positions et orientations du médiator lors du grattage, fournissant une base expérimentale Ąable pour déĄnir la cinématique du mécanisme.
Les données issues de lŠanalyse vidéo servent à valider les modèles cinématiques et à orienter la conception mécanique, assurant ainsi que le dispositif reproduira Ądèlement les mouvements réels du médiator.

14

Étude et conception du système de grattage | Conception du dispositif

### 2.3.2 Conception mécanique et simulation sous SolidWorks

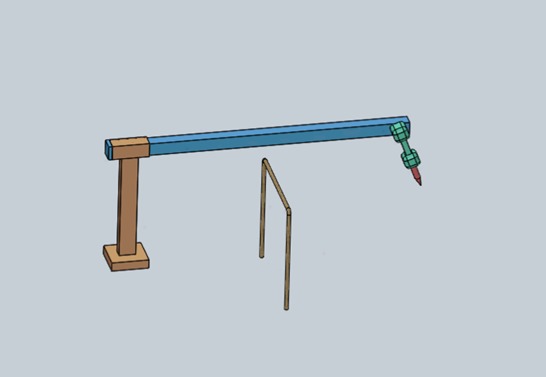
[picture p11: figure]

Figure 2.4 Ű simulation du comportement du mediator sur solidworks.

Sur la base des données cinématiques, une conception mécanique détaillée a été réalisée sous SolidWorks. Cette étape inclut la modélisation 3D du mécanisme, permettant dŠintégrer les degrés de liberté nécessaires, de vériĄer lŠencombrement et dŠanticiper les contraintes mécaniques.
Les assemblages sont simulés pour tester la mobilité, éviter les collisions et garantir la robustesse structurelle avant fabrication.

### 2.3.3 Simulation numérique du mouvement sous Python

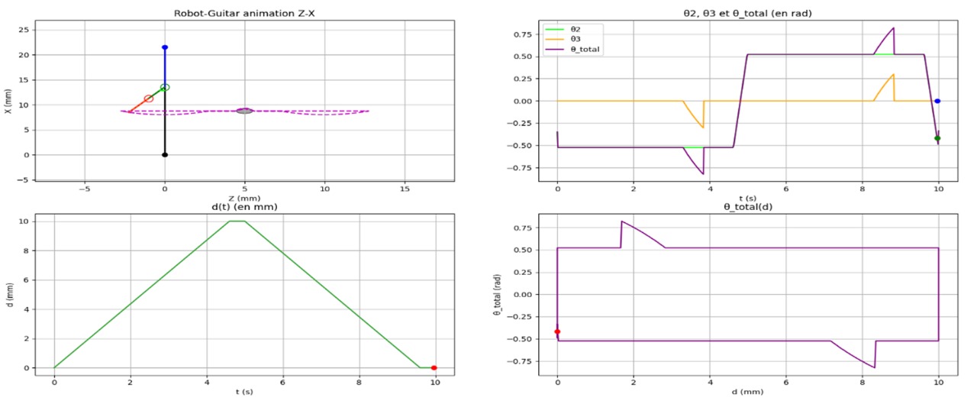
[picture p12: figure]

(a) Simulation Python de la trajectoire du médiator .

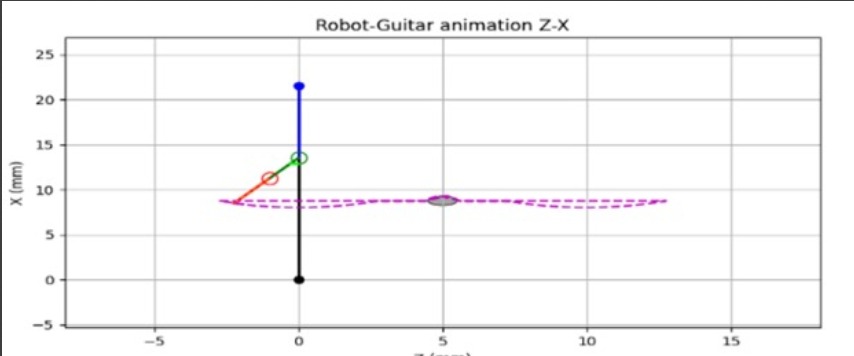
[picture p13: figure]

(b) Simulation Python de la trajectoire du médiator en fonction du déplacement d1.
Figure 2.5 Ű Simulation Python de la trajectoire du médiator à partir des paramètres DH et des variables cinématiques (θ2, d1).

La simulation numérique, développée sous Python, joue un rôle central dans la validation du comportement dynamique du médiator. Elle repose sur un modèle géométrique enrichi intégrant un degré de liberté dit ń angle passif ż qui représente précisément lŠorientation du médiator durant le contact avec la corde.

15

Étude et conception du système de grattage | Conception du dispositif

Les objectifs principaux de cette simulation sont :
- modéliser lŠangle dŠattaque du médiator par rapport à la corde ;
- représenter correctement le passage du médiator dŠun côté à lŠautre de la corde, notamment lors du sweep picking ;
- analyser la géométrie du balayage pour éviter les conĄgurations mécaniquement impossibles ou dangereuses ;
- valider la faisabilité cinématique du mouvement avant toute réalisation physique. Les résultats sont visualisés en 2D (plan xŰz) pour observer la forme de la trajectoire, lŠinĆuence des paramètres géométriques, ainsi que lŠévolution de lŠorientation du médiator. Ces analyses permettent dŠajuster le modèle, optimiser le mécanisme, et préparer efficacement la phase de conception mécanique.

16

Réalisation et intégration du système

# Chapitre 3

# Réalisation et intégration du système

## 3.1 Introduction générale

Les résultats issus de la modélisation théorique et des simulations ont permis de valider le choix du mécanisme retenu. La trajectoire générée correspond exactement au mouvement requis pour un balayage de type sweep picking, sans risque de collision et en respectant les contraintes mécaniques du système.
La simulation a révélé plusieurs points clés :

→ Le déplacement linéaire d1 permet de couvrir toute la zone fonctionnelle devant la corde.
→ La rotation angulaire θ2 génère lŠarc nécessaire pour simuler le grattage.
→ LŠensemble du mécanisme fonctionne dans des positions mécaniquement réalisables. → La trajectoire obtenue est conforme au geste recherché.

Ces observations confortent le choix structurel, qui offre un mouvement reproductible, simple à piloter et compatible avec les capacités des actionneurs sélectionnés.

LŠétape suivante consiste à dimensionner précisément les composants mécaniques et déĄnir les paramètres techniques pour la réalisation physique conforme à la trajectoire simulée.

## 3.2 Partie mécanique

### 3.2.1 Présentation des pièces imprimées

La partie mécanique est constituée de plusieurs pièces imprimées en 3D et dŠéléments mécaniques standards. Chaque composant a été conçu pour répondre à un rôle précis dans le mécanisme.

17

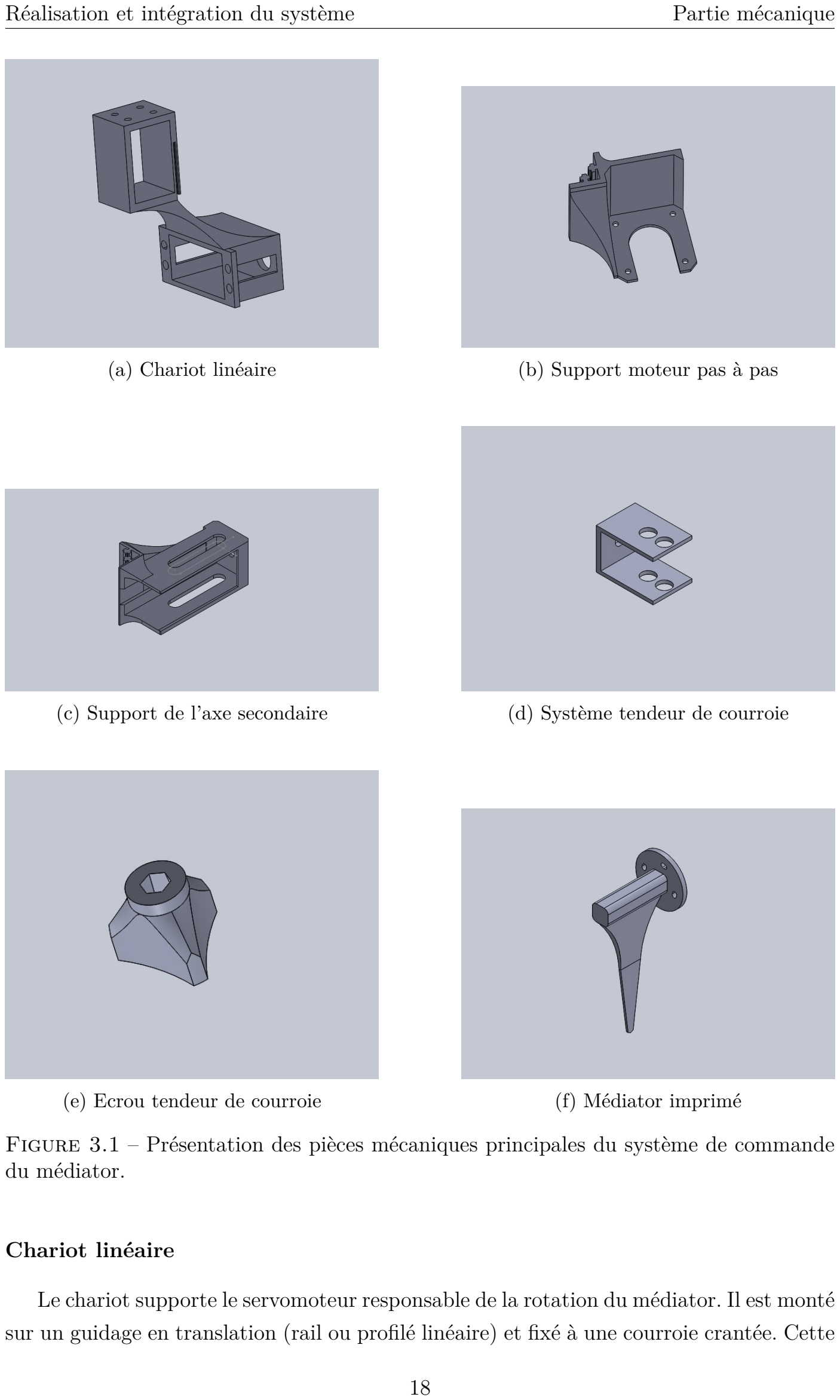
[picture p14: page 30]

Réalisation et intégration du système | Partie mécanique
(a) Chariot linéaire | (b) Support moteur pas à pas
(c) Support de l’axe secondaire | (d) Système tendeur de courroie
(e) Ecrou tendeur de courroie | (f) Médiator imprimé
Figure 3.1 Ű Présentation des pièces mécaniques principales du système de commande du médiator.

Chariot linéaire

Le chariot supporte le servomoteur responsable de la rotation du médiator. Il est monté sur un guidage en translation (rail ou proĄlé linéaire) et Ąxé à une courroie crantée. Cette

18

Réalisation et intégration du système | Partie mécanique

courroie est entraînée par un moteur pas à pas pour assurer le mouvement linéaire.
Le chariot intègre des points de Ąxation renforcés pour garantir la rigidité et limiter les vibrations susceptibles dŠaltérer la précision du mouvement.

Fonction : Permet la translation linéaire sur la course déĄnie (jusquŠà 125 mm), garantissant un positionnement précis du servomoteur devant la corde.

Support moteur pas à pas

Un support imprimé Ąxe le moteur pas à pas NEMA 17 sur la structure principale. Ce support assure :
→ Une Ąxation rigide réduisant les jeux mécaniques.
→ Le bon positionnement en hauteur et en alignement avec la poulie crantée.
→ La transmission directe du couple au système de courroie.

Caractéristique : Impression 3D avec un remplissage renforcé (50%) pour assurer la solidité, avec intégration possible de passages pour visserie standard M3.

Support de lŠaxe secondaire

Ce support porte lŠaxe sur lequel tourne la poulie de renvoi de la courroie. Il est conçu pour maintenir un alignement parfait et minimiser les frottements.

Système tendeur de courroie

Constitué dŠune pièce tendeur imprimée en 3D et dŠune vis de réglage avec un écrou imprimé pour faciliter la manipulation. Ce système permet :
→ Le réglage Ąn de la tension de la courroie.
→ Le montage et démontage rapide de la courroie sans démontage complet.
→ LŠélimination des jeux pouvant entraîner des glissements et une perte de précision.

Avantages : La possibilité de régler la tension avec précision garantit la répétabilité du mouvement et la longévité du mécanisme.

Médiator imprimé

Un médiator spécialement conçu avec un matériau souple mais résistant est Ąxé directement sur lŠaxe de sortie du servomoteur FUTABA S3003.

Propriétés recherchées : Souplesse suffisante pour ne pas abîmer la corde, mais assez rigide pour produire un grattage audible et efficace.

19

Réalisation et intégration du système | Partie mécanique

Conception : Le remplissage et lŠépaisseur sont ajustés pour optimiser la force de frappe et la durabilité.

### 3.2.2 Architecture mécanique générale

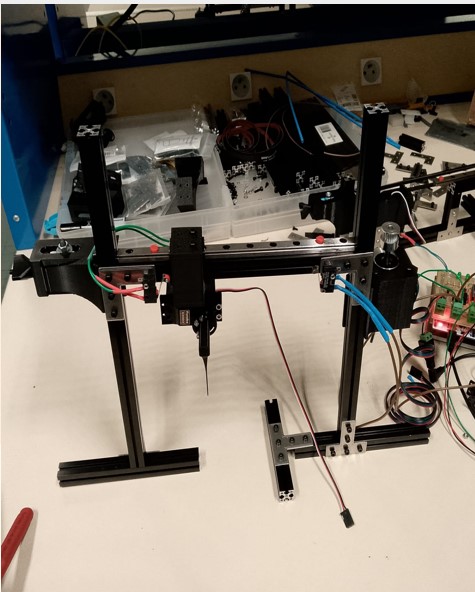
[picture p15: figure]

Figure 3.2 Ű Vue dŠensemble de lŠassemblage mécanique avec indication des principaux composants.

Le moteur pas à pas est monté sur la structure Ąxe du système via un support imprimé en 3D, qui relie mécaniquement le moteur au châssis principal. LŠaxe moteur entraîne une poulie crantée, laquelle transmet le mouvement linéaire au chariot.
Un tendeur permet dŠéliminer tout jeu dans la courroie, assurant une grande précision et répétabilité dans le déplacement.
La course maximale est de 125 mm, correspondant à environ 8 frettes virtuelles selon la longueur de la corde utilisée.

20

Réalisation et intégration du système | Partie électronique

## 3.3 Partie électronique

### 3.3.1 Conception générale

Le système électronique a été conçu pour être modulaire, Ąable et adapté à un usage pédagogique, favorisant la compréhension et la maintenance.
LŠalimentation principale est unique, en 12 V, à partir de laquelle sont générées les tensions spéciĄques nécessaires aux différents composants.

### 3.3.2 Matériaux et composants utilisés

→ Carte STM32 Nucleo STM32F411RE : Microcontrôleur principal assurant la gestion temps réel des actionneurs et capteurs.
→ Servomoteur FUTABA S3003 : Actionneur pour la rotation du médiator.
→ Moteur pas à pas NEMA 17 : Assure la translation linéaire.
→ Pilote DRV8825 : Contrôle précis du moteur pas à pas avec microstepping (1/32). → AmpliĄcateur audio LM386 : Conditionnement du signal microphonique pour acquisition audio.
→ Régulateur 7806 : Conversion de la tension 12 V vers 6 V pour le servomoteur. → Composants passifs : Résistances, condensateurs, fusibles de protection, LEDs de signalisation.

### 3.3.3 Architecture électronique modulaire

Le système est divisé en deux cartes principales montées en sandwich autour de la carte STM32 Nucleo :
Carte de commande mécanique : Contient le DRV8825, régulateur 7806, connecteurs moteurs, LEDs et protection.
Carte dŠacquisition audio : Comprend le circuit dŠampliĄcation, conditionnement du signal microphone et points dŠaccès pour oscilloscope.
Cette modularité facilite lŠassemblage, le dépannage et permet la réutilisation de chaque module dans dŠautres projets pédagogiques.

### 3.3.4 Caractéristiques électriques

→ Alimentation : 12 V principale, stable et protégée.
→ Servomoteur : Alimentation en 6 V régulée, courant maximal 500 mA.
→ Moteur pas à pas : Alimentation 12 V, courant par phase réglé à 1 A max via potentiomètre DRV8825.

21

Réalisation et intégration du système | Partie informatique

→ Protection : Fusibles en série sur les lignes critiques, LEDs de statut.

## 3.4 Partie informatique

### 3.4.1 Microcontrôleur et périphériques utilisés

Le système est piloté par un STM32F411RE sur carte Nucleo, avec les périphériques suivants conĄgurés :

→ TIM1 : Génération du signal de commande du moteur pas à pas avec gestion des interruptions.
→ TIM4 : Génération du signal PWM pour servomoteur (période 20 ms, fréquence 50 Hz).
→ TIM5 : Chronométrage haute résolution pour temporisations Ąnes.
→ DMA : Optimisation des transferts ADC et USART.
→ USART2 : Communication série bidirectionnelle avec gestion par interruptions et DMA.
→ GPIO : Gestion des sorties moteurs, capteurs et entrées avec interruptions.

### 3.4.2 Organisation logicielle

Le contrôle logiciel sŠappuie sur une architecture modulaire avec des fonctions dédiées :

⋆ set_servo_position(uint8_t angle) : Calcule et applique le rapport cyclique PWM pour positionner le servomoteur.
⋆ play_note() : Alterne entre deux positions prédéĄnies du servomoteur pour simuler le coup de médiator.
⋆ chariot() : Alterne entre deux positions prédéĄnies du servomoteur et du moteur pour simuler le coup de médiator.
⋆ calculate_steps_speed() : Calcule la trajectoire en nombre de pas et génère un proĄl trapézoïdal de vitesse.
⋆ configure_timer1_for_velocity() : Met à jour les registres pour générer la fréquence adéquate.
⋆ HAL_TIM_PeriodElapsedCallback() : Exécute chaque pas moteur et stoppe le mouvement à la position cible.

Le système fonctionne en boucle ouverte, avec une procédure de homing utilisant un capteur de Ąn de course en interruption pour établir la référence de position.

22

Réalisation et intégration du système | Partie informatique

### 3.4.3 Machine à états pour la coordination

La gestion globale sŠappuie sur une machine à états décrite ainsi :
⋆ État 0 : Système non calibré Ů homing à effectuer.
⋆ État 1 : Moteur activé sans référence.
⋆ État 2 : Homing en cours.
⋆ État 3 : Position référencée, système prêt.
⋆ État 4 : Déplacement actif.
Les transitions sont déclenchées par des événements (interruptions, commandes UART, temporisations).

### 3.4.4 Protocole de communication UART

Le système reçoit des commandes au format ASCII via UART, interprétées par la
fonction interpret_command().
Les commandes principales sont :
:E1 / :E0 Activation / désactivation du moteur.
:H Déclenchement de la procédure de homing.
:PXXX Déplacement à la position absolue XXX (en pas ou unité déĄnie).
:I Oscillation simple du servomoteur et moteur entre deux positions prédéĄnies. :J Oscillation continue.
:K Arrêt de lŠoscillation.

### 3.4.5 Interface utilisateur graphique et ajout de la commande

du médiator

Pour la partie interface utilisateur graphique (GUI), nous avons choisi de reprendre celle développée par nos prédécesseurs. Cette interface a déjà fait ses preuves en termes de convivialité et de fonctionnalité, ce qui nous a permis de gagner du temps sur la conception logicielle et de nous concentrer sur les améliorations spéciĄques à notre projet.
Nous y avons intégré une nouvelle commande dédiée au contrôle du médiator, permettant de piloter précisément son mouvement de rotation via lŠinterface. Cette commande facilite la gestion synchronisée entre le servomoteur actionnant le médiator et le moteur pas à pas responsable du déplacement linéaire, offrant ainsi un contrôle plus Ćuide et intuitif du robot guitariste.
Cette extension de lŠinterface graphique conserve la modularité et la simplicité de lŠoriginal, tout en augmentant les capacités du système sans complexiĄer lŠexpérience utilisateur.

23

Compétences et responsabilité professionnelle

# Chapitre 4

# Compétences et responsabilité professionnelle

## 4.1 Compétences techniques développées

Au cours de ce PPE, jŠai acquis et consolidé un ensemble de compétences techniques directement applicables au domaine de la mécatronique et de la robotique. Ces compétences couvrent lŠensemble du cycle de conception, de simulation et dŠintégration dŠun système complexe.
⋆ Modélisation cinématique avancée : élaboration complète des modèles de Denavit-Hartenberg pour chaque mécanisme, adaptation des paramètres pour reproduire Ądèlement le mouvement réel, vériĄcation par simulation numérique des trajectoires et des vitesses.
⋆ Conception et analyse mécanique : comparaison et optimisation des structures, étude des contraintes et des sollicitations, choix des solutions garantissant précision, robustesse et facilité dŠintégration.
⋆ Simulation numérique et validation : développement de scripts Python pour le calcul des positions, vitesses et accélérations, analyse des écarts par rapport aux modèles théoriques, interprétation critique des résultats pour ajustements.
⋆ Intégration électronique et capteurs : mise en œuvre des capteurs, actionneurs et interfaces de communication, synchronisation avec le modèle mécanique et véri-Ącation du fonctionnement global.
⋆ Logiciels professionnels de conception : utilisation de SolidWorks pour la modélisation des pièces, assemblages et simulations mécaniques, préparation des Ąchiers pour impression 3D ou tests expérimentaux.
⋆ Gestion et documentation technique : rédaction structurée des rapports, création de schémas cinématiques, diagrammes explicatifs, organisation et archivage des résultats expérimentaux et simulations.

24

Compétences et responsabilité professionnelle Travail personnel et responsabilités

## 4.2 Travail personnel et responsabilités

Personnellement, jŠai été responsable de plusieurs volets critiques du projet, impliquant à la fois la conception, lŠanalyse et lŠintégration.
→ Modélisation complète des mécanismes : construction et ajustement des modèles cinématiques pour représenter Ądèlement le comportement des articulations et chaînes cinématiques.
→ Développement des outils de simulation : création et paramétrage des scripts Python pour simuler trajectoires, vitesses et accélérations, production de courbes et graphiques pour validation.
→ Analyse critique et optimisation : étude comparative des conĄgurations mécaniques, identiĄcation des points faibles, proposition et justiĄcation des modiĄcations techniques.
→ Intégration globale du système : coordination avec lŠensemble de lŠéquipe pour assurer la cohérence mécanique, électronique et logicielle, vériĄcation des interactions entre sous-systèmes.
→ Amélioration et Ąabilisation : propositions pour augmenter la précision, la répétabilité et la robustesse des mécanismes, vériĄcation par simulations et tests expérimentaux.
→ Documentation et communication technique personnelle : création de schémas détaillés, diagrammes de Ćux, tableaux de résultats, rapports techniques et présentations pour chacune des étapes réalisées.

## 4.3 Compétences dŠingénieur mobilisées

Ce projet mŠa permis de mettre en pratique et de consolider les compétences fondamentales attendues dŠun ingénieur :
- Analyse et déĄnition des besoins : identiĄcation des contraintes techniques, fonctionnelles et temporelles, formulation des spéciĄcations.
- Modélisation et abstraction : formalisation des mécanismes, structuration des modèles mathématiques et physiques pour permettre simulation et validation.
- JustiĄcation et choix techniques : évaluation et sélection des solutions en tenant compte de la faisabilité, des coûts, de la durabilité et des contraintes dŠintégration.
- Travail en équipe et coordination : collaboration avec les membres du groupe, partage des résultats et harmonisation des livrables pour un système intégré.
- Communication technique et documentation : rédaction de rapports détaillés, présentation claire des résultats, schémas et analyses pour les enseignants et le jury.

25

Compétences et responsabilité professionnelle Responsabilité environnementale et sociale

- Prise en compte des contraintes réelles : considération des limites mécaniques, électroniques et logicielles pour garantir la robustesse et la Ąabilité du système.

## 4.4 Responsabilité environnementale et sociale

Le projet intègre également une dimension de responsabilité sociétale et environnementale, indispensable dans la pratique professionnelle.

### 4.4.1 Enjeux environnementaux

⋆ Rationalisation des matériaux : limitation de la consommation, utilisation judicieuse et durable des ressources.
⋆ Fabrication additive : recours à lŠimpression 3D pour réduire les déchets et faciliter la production de prototypes.
⋆ Conception modulaire et réutilisable : choix de solutions permettant démontage, réparation et réemploi des composants.

### 4.4.2 Enjeux sociaux et pédagogiques

→ Travail collaboratif : partage de connaissances et compétences au sein de lŠéquipe. → Formation professionnelle : développement de lŠautonomie, de lŠesprit critique et de la responsabilité individuelle dans un contexte de projet collectif.
→ Engagement et implication : chaque étudiant contribue de manière signiĄcative à la réussite du projet.

### 4.4.3 Responsabilité et durabilité du projet

- Conception évolutive : système prévu pour être réutilisé et amélioré par les promotions futures, réduisant la production de prototypes redondants.
- Démarche durable : intégration de critères environnementaux et sociaux dès la phase de conception, limitant lŠimpact global du projet.
- Transparence et traçabilité : documentation complète des choix, modèles et tests pour assurer un suivi Ąable et reproductible.

26

Conclusion

# Conclusion

## Difficultés rencontrées

Au cours de ce projet, plusieurs difficultés ont été rencontrées dans les domaines suivants :

Difficultés mécaniques

- Précision du guidage linéaire : Assurer un déplacement Ćuide sans jeu ni frottements excessifs a nécessité plusieurs itérations sur la conception et le choix des matériaux.
- Rigidité des pièces imprimées : Certaines pièces 3D initialement conçues présentaient des déformations sous charge, obligeant à revoir lŠépaisseur ou le remplissage.
- Tension et alignement de la courroie : Trouver le bon réglage de tension a été critique pour éviter le glissement et garantir la précision des déplacements.

Difficultés électroniques

- Gestion de lŠalimentation : Adapter les tensions aux différents composants tout en assurant la stabilité du système a demandé la mise en place de régulateurs efficaces et de protections.
- Bruit électrique : Le bruit généré par le moteur pas à pas a perturbé la lecture audio, nécessitant un blindage et une séparation soignée des câbles.
- Pilote moteur : ConĄgurer correctement le driver DRV8825 pour un microstepping optimal a demandé plusieurs tests et ajustements.

Difficultés informatiques

- Synchronisation des mouvements : La coordination entre les moteurs linéaires et rotatifs a nécessité une gestion Ąne des interruptions et temporisations.
- Gestion des interruptions UART et timers : Garantir une communication Ćuide sans perte de données a été complexe en raison des contraintes temps réel.

27

Conclusion

- Mise en place de la machine à états : Concevoir une architecture logicielle robuste et évolutive a demandé une réĆexion approfondie pour anticiper tous les cas dŠutilisation.

## Perspectives dŠamélioration

Plusieurs axes dŠamélioration sont envisageables pour optimiser et enrichir ce système : ⋆ Ajout de capteurs de position absolue : Pour un contrôle en boucle fermée améliorant la précision et la répétabilité.
⋆ Amélioration du médiator : Utilisation de matériaux plus performants pour un meilleur rendu sonore et une meilleure durabilité.
⋆ Optimisation de lŠarchitecture logicielle : Passage à un RTOS pour gérer les tâches en temps réel avec plus de Ćexibilité.
⋆ Modularisation du système : Permettre le changement facile des composants (types de moteurs, capteurs, actionneurs) selon les besoins.
⋆ Ajout de fonctionnalités musicales avancées : Comme la reconnaissance automatique des notes ou le jeu en mode autonome avec intelligence artiĄcielle.

## Conclusion générale

Ce projet de conception et réalisation dŠun robot guitariste a permis de mettre en pratique de nombreuses compétences multidisciplinaires, mêlant mécanique, électronique et informatique.
Grâce à une modélisation rigoureuse et à une intégration soignée des différents composants, le système Ąnal est capable de simuler avec précision un mouvement de balayage sur une corde de guitare, reproduisant Ądèlement la technique du sweep picking. LŠensemble des parties mécanique, électronique et logicielle a été pensé pour fonctionner en synergie, assurant ainsi une grande Ąabilité et répétabilité du geste.
Ce projet a été une expérience très enrichissante, confrontant à des problématiques réelles dŠingénierie multidisciplinaire.
Il a permis dŠacquérir une solide maîtrise des techniques de modélisation, de conception mécanique, dŠélectronique embarquée et de programmation microcontrôleur.
La réussite de la réalisation expérimentale démontre la pertinence des choix techniques effectués, tout en laissant une marge dŠévolution importante grâce aux pistes dŠamélioration identiĄées.
Cette expérience ouvre ainsi la voie à de futurs projets plus complexes dans le domaine de la robotique musicale et de lŠinterfaçage intelligent entre lŠélectronique et la musique.

28

Bibliographie | Bibliographie

# Bibliographie

[1] Juan Marcos De Miguel, Facundo Arito, Realización de un Robot-Guitarra, Rapport de projet, juillet 2025.

I

Mises en plan des pièces imprimées en 3D

II

# Annexe A

# Mises en plan des pièces imprimées

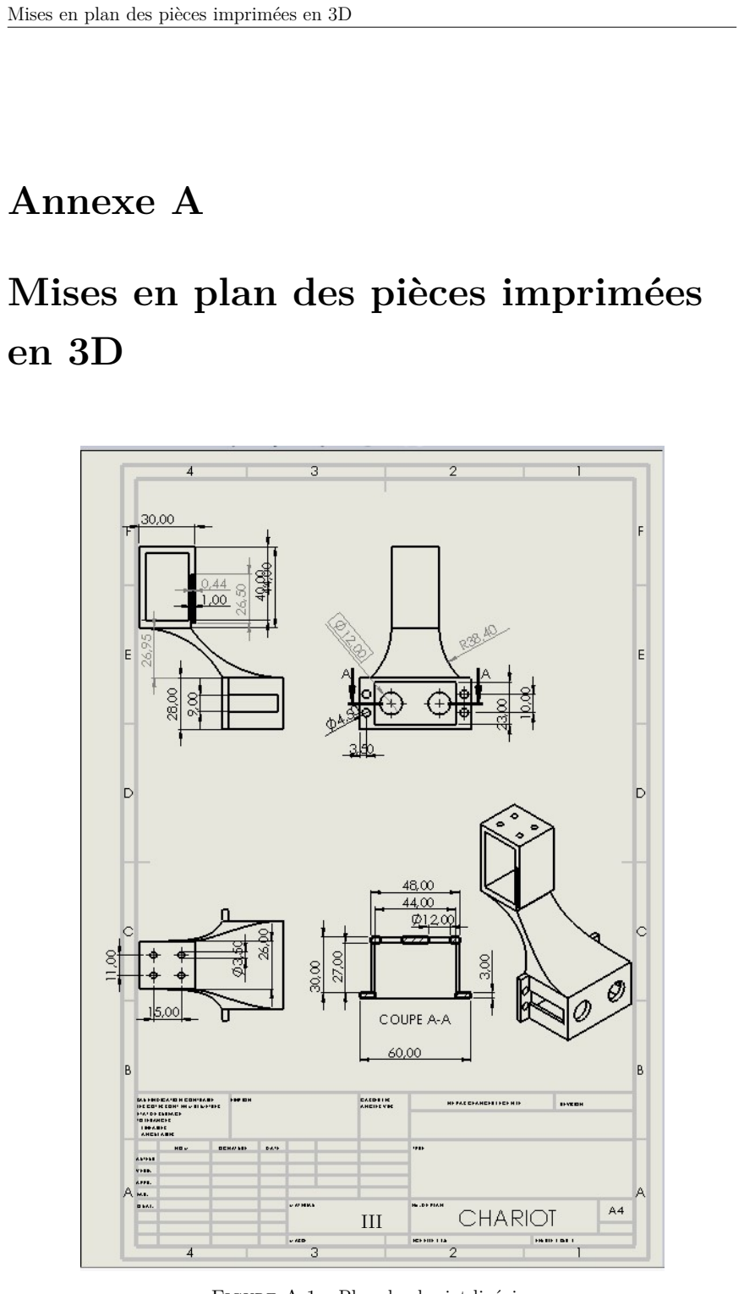
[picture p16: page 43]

Mises en plan des pièces imprimées en 3D

# en 3D

Figure A.1 Ű Plan du chariot linéaire

III

Mises en plan des pièces imprimées en 3D

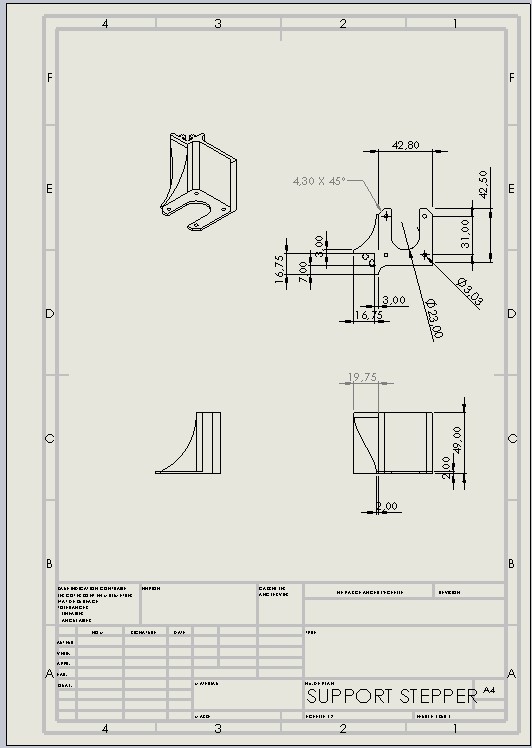
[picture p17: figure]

Figure A.2 Ű Plan du support moteur pas à pas

IV

Mises en plan des pièces imprimées en 3D

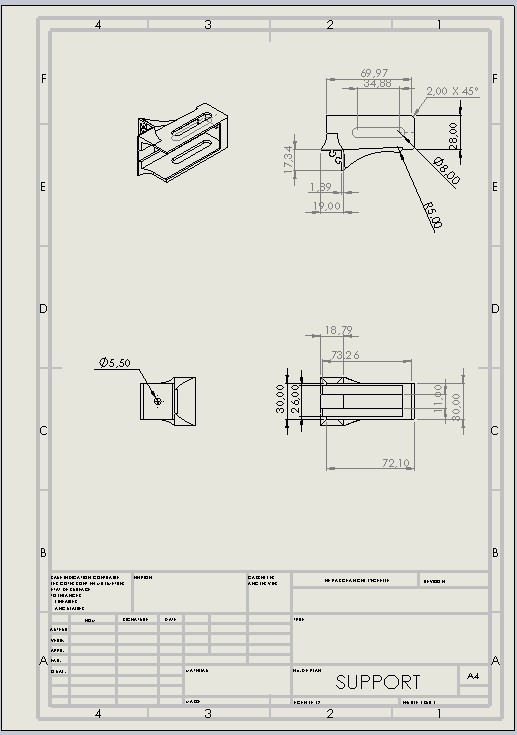
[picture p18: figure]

Figure A.3 Ű Plan du support de lŠaxe secondaire

V

Mises en plan des pièces imprimées en 3D

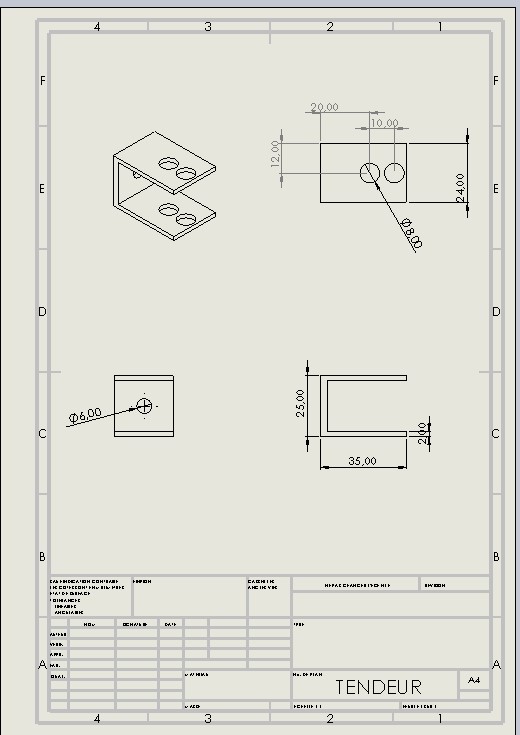
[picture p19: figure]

Figure A.4 Ű Plan du système tendeur de courroie

VI

Mises en plan des pièces imprimées en 3D

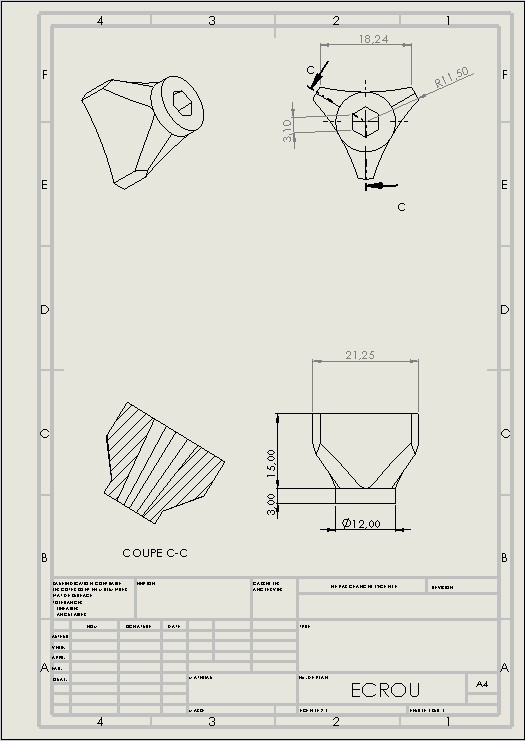
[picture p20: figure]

Figure A.5 Ű Plan de lŠécrou tendeur de courroie

VII

Mises en plan des pièces imprimées en 3D

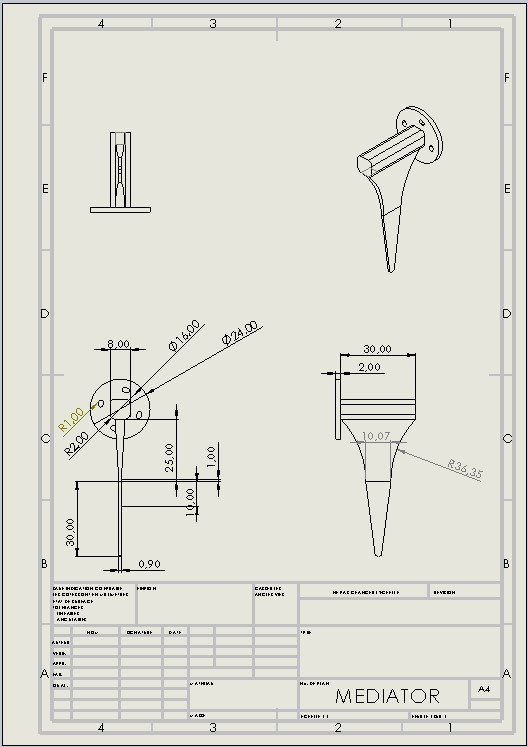
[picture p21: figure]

Figure A.6 Ű Plan du médiator imprimé

VIII

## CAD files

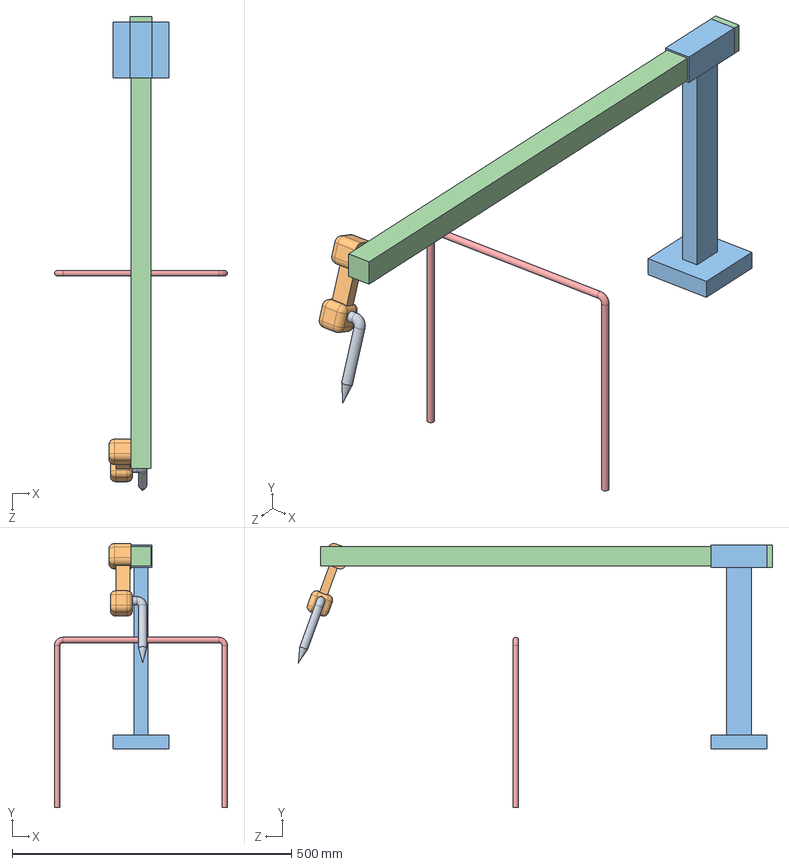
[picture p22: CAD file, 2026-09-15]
cao-solidworks/Assemblage varié.SLDASM
310.0 x 472.8 x 849.4 mm
BRAS MEDIATOR
BRAS ROB
SUPPORT
TIGE
CORDE

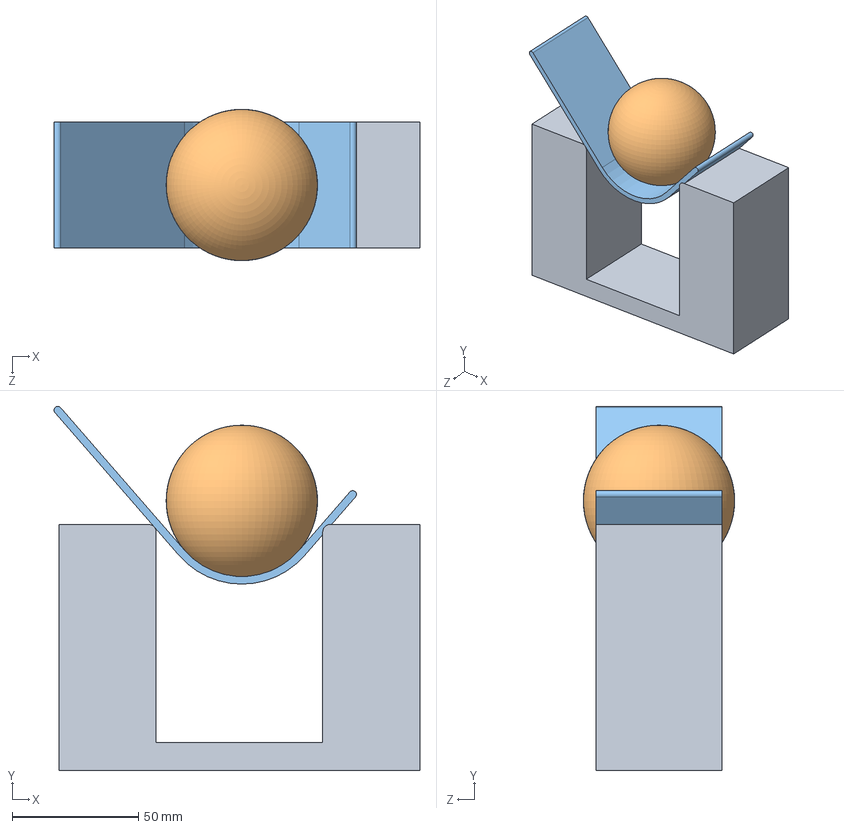
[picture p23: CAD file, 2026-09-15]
cao-solidworks/Assemblage1.SLDASM
145.1 x 144.4 x 60.0 mm
Pièce1u^Assemblage1
Pièce2B^Assemblage1
Pièce3P^Assemblage1

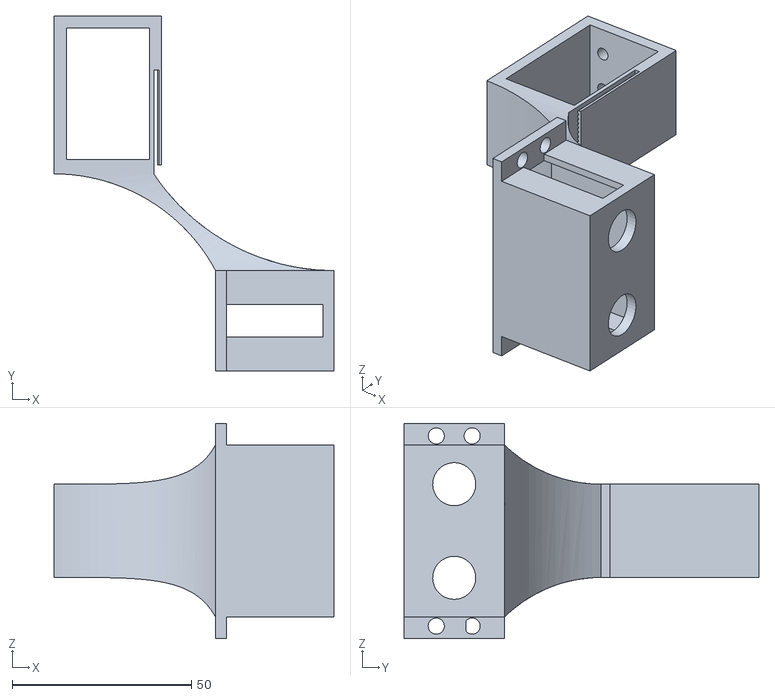
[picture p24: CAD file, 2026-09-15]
cao-solidworks/MONTAGE/IMPRESSION/chariot.STL
78.0 x 99.0 x 60.0

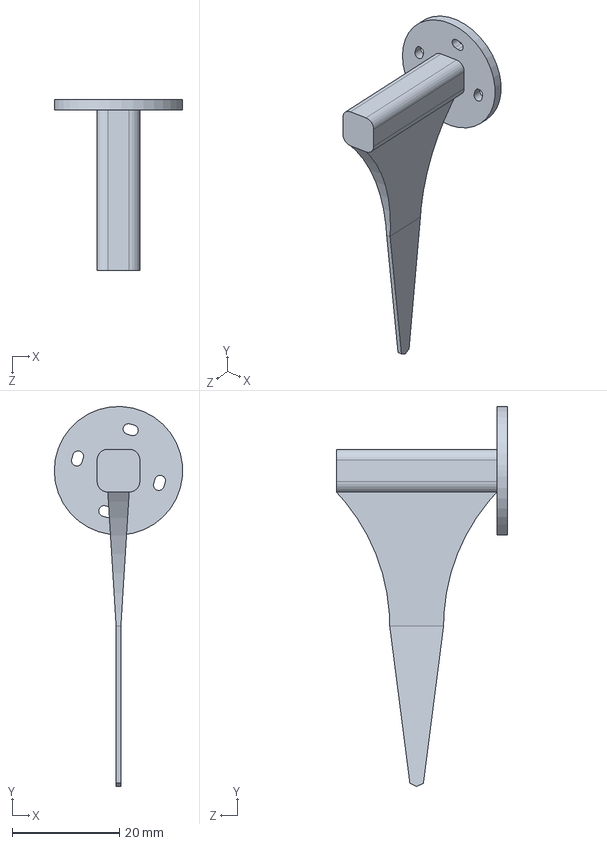
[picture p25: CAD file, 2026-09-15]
cao-solidworks/MONTAGE/MEDIATOR.SLDPRT
24.0 x 71.0 x 32.0 mm

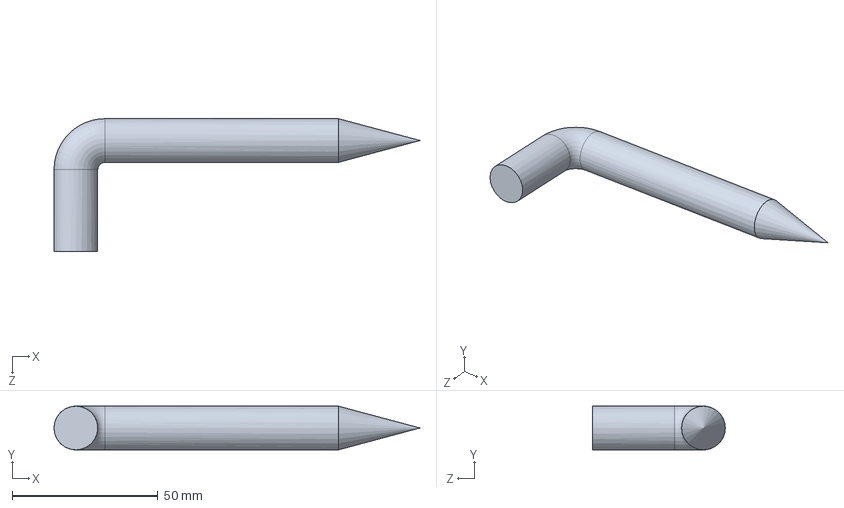
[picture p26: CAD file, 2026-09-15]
cao-solidworks/BRAS MEDIATOR.SLDPRT
125.5 x 15.0 x 45.5 mm

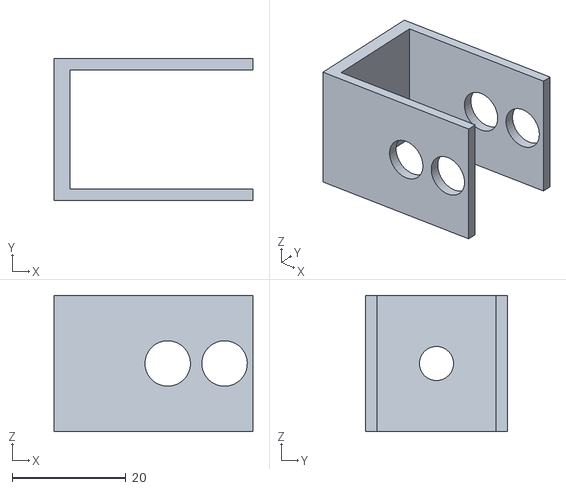
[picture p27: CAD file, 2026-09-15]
cao-solidworks/MONTAGE/IMPRESSION/PIECE BLEU.STL
35.0 x 25.0 x 24.0

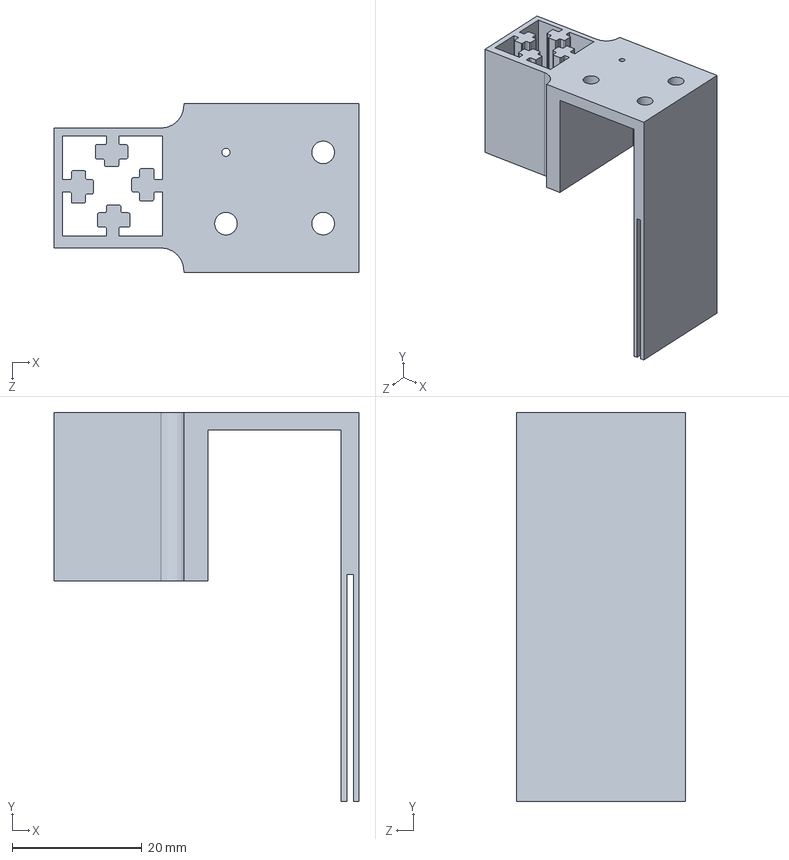
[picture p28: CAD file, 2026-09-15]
cao-solidworks/MONTAGE/Pièce2.SLDPRT
47.0 x 60.0 x 26.0 mm

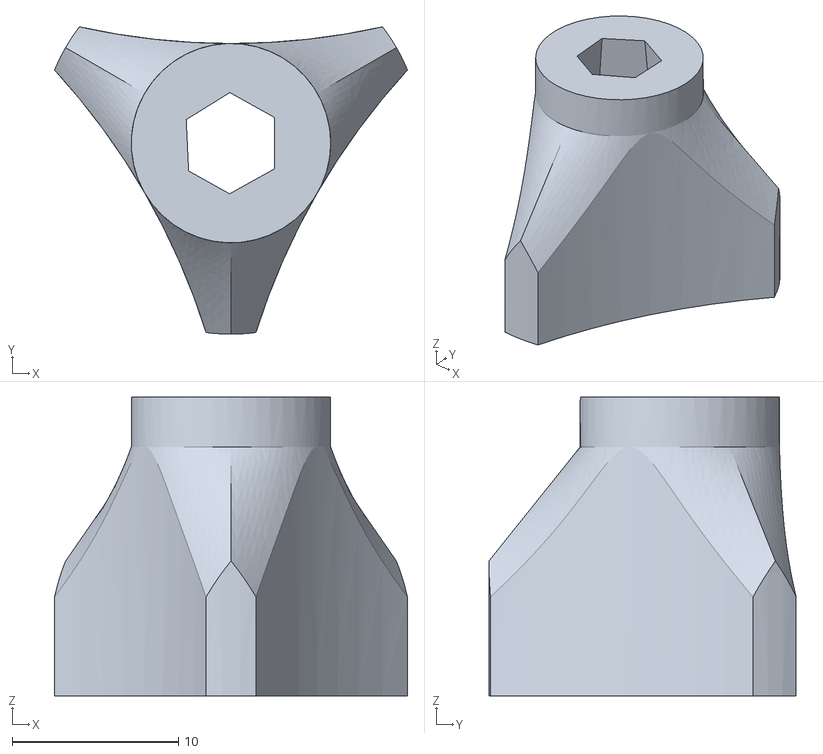
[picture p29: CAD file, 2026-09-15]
cao-solidworks/MONTAGE/IMPRESSION/ECROU.STL
21.3 x 18.5 x 18.0

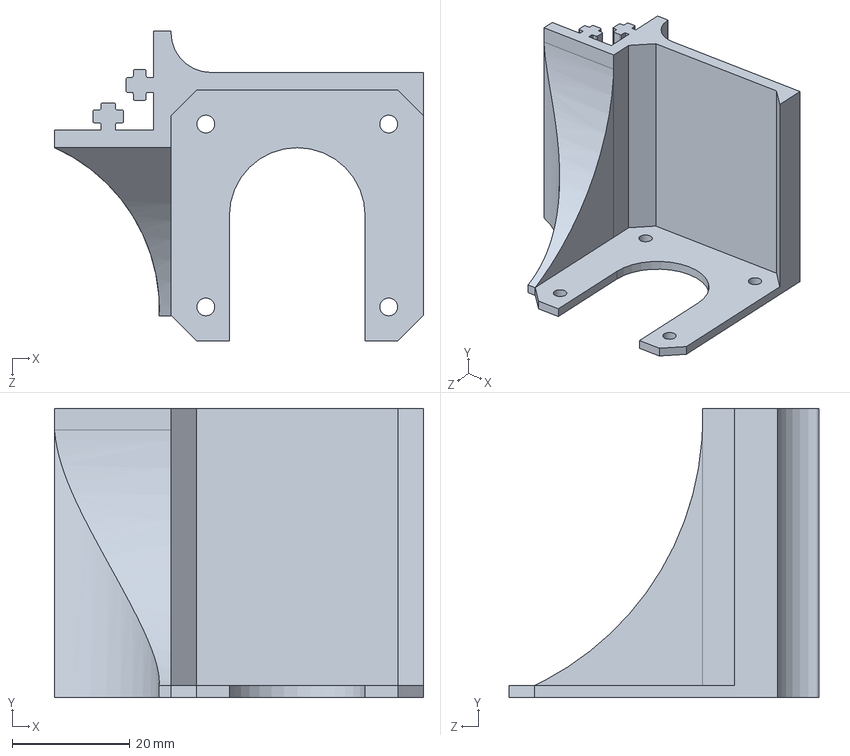
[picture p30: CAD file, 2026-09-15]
cao-solidworks/MONTAGE/Pièce1.SLDPRT
62.5 x 49.0 x 52.5 mm

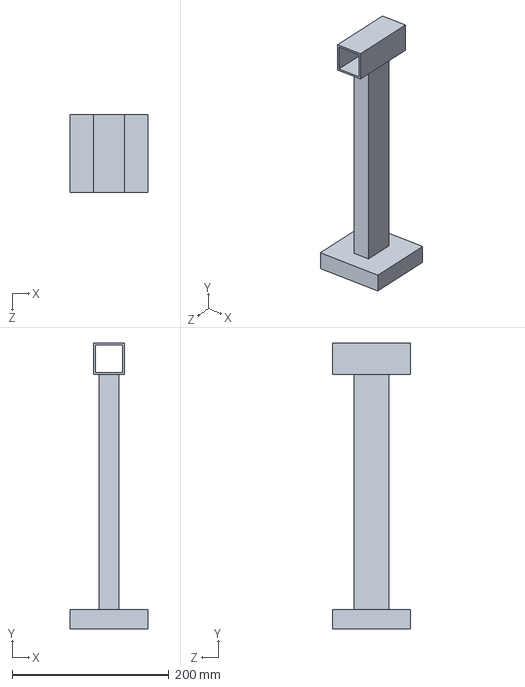
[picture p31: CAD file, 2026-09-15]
cao-solidworks/SUPPORT.SLDPRT
100.0 x 365.0 x 100.0 mm

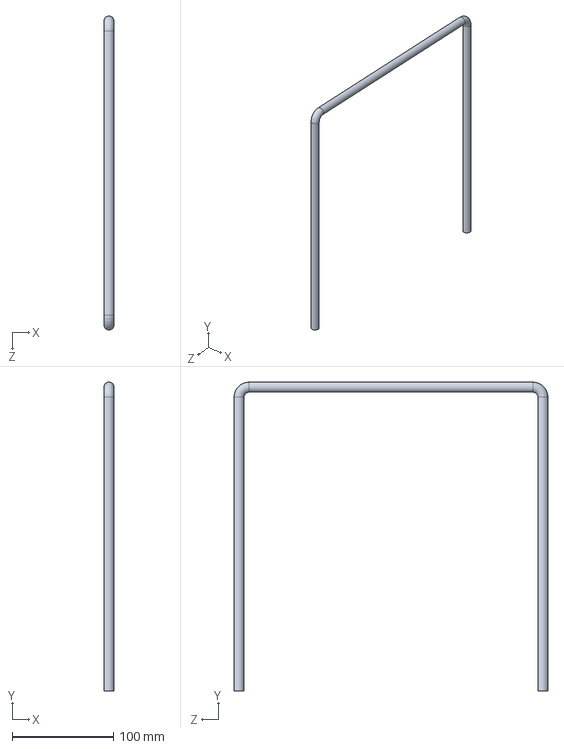
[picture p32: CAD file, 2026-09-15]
cao-solidworks/CORDE.SLDPRT
10.0 x 305.0 x 310.0 mm

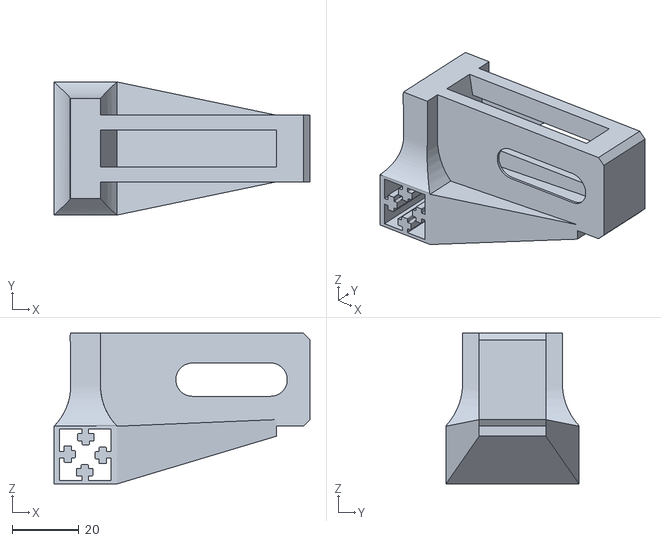
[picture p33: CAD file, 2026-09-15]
cao-solidworks/MONTAGE/IMPRESSION/Pièce3.STL
77.0 x 40.0 x 45.3

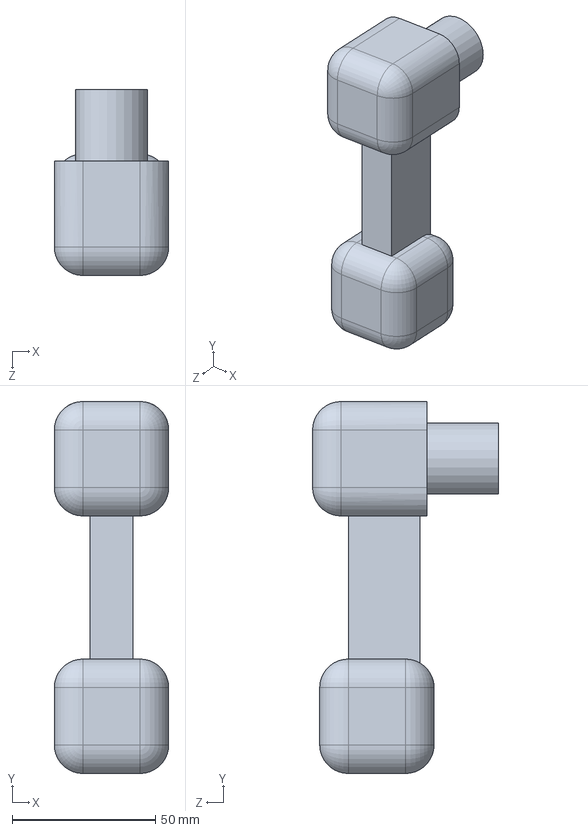
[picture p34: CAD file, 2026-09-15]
cao-solidworks/BRAS ROB.SLDPRT
40.0 x 130.0 x 65.0 mm

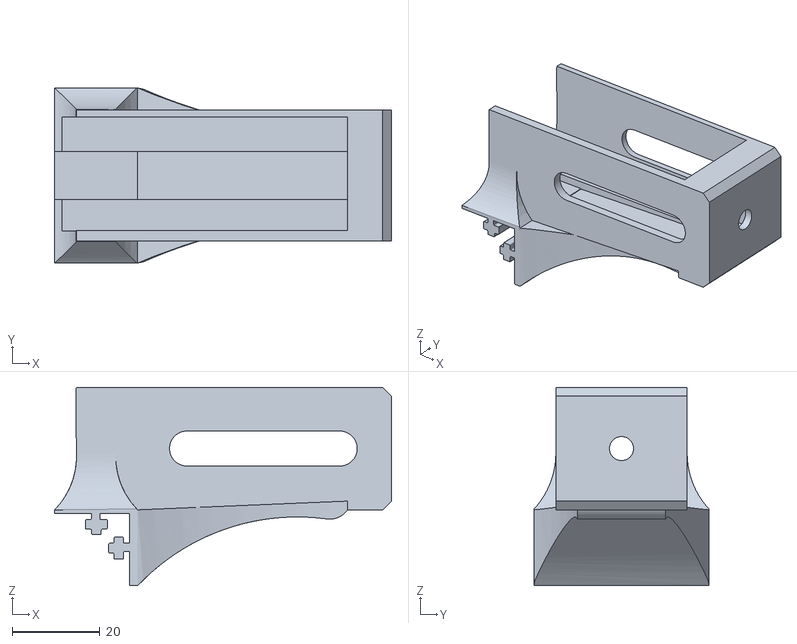
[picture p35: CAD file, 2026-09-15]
cao-solidworks/MONTAGE/IMPRESSION/TENDEUR.STL
77.0 x 40.0 x 45.3

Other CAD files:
cao-solidworks/MONTAGE/PIECE BLEU.SLDPRT
cao-solidworks/MONTAGE/IMPRESSION/MEDIATOR.STL
cao-solidworks/MONTAGE/ECROU.SLDPRT
cao-solidworks/MONTAGE/Pièce3.SLDPRT
cao-solidworks/MONTAGE/IMPRESSION/Pièce1.STL
cao-solidworks/MONTAGE/IMPRESSION/Pièce2.STL
cao-solidworks/MONTAGE/MISE EN PLAN/CHARIOT.SLDDRW
cao-solidworks/MONTAGE/MISE EN PLAN/ECROU.SLDDRW
cao-solidworks/MONTAGE/MISE EN PLAN/MEDIATOR.SLDDRW
cao-solidworks/MONTAGE/MISE EN PLAN/SUPPORT STEPPER.SLDDRW
cao-solidworks/MONTAGE/MISE EN PLAN/SUPPORT.SLDDRW
cao-solidworks/MONTAGE/MISE EN PLAN/TENDEUR.SLDDRW
cao-solidworks/MONTAGE/chariot.SLDPRT
cao-solidworks/TIGE.SLDPRT

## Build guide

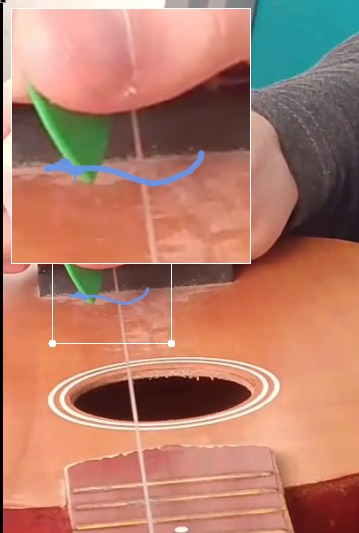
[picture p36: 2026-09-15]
cao-solidworks/MONTAGE/image/trajectoire_mediator.jpeg

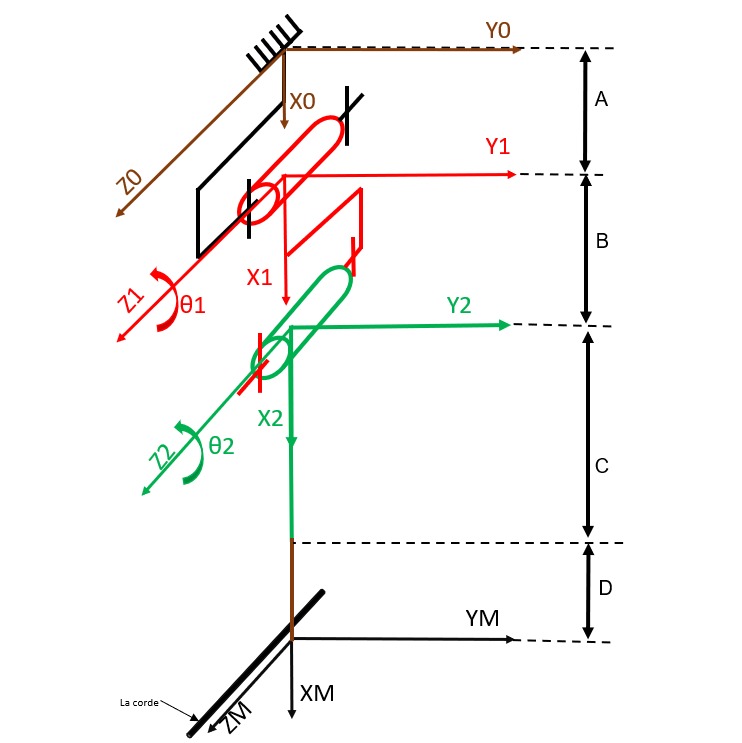
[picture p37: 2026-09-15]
cao-solidworks/MONTAGE/image/mécanisme_double-rotation_2DDL.jpeg

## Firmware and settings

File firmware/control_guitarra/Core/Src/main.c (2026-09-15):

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
/* Includes ------------------------------------------------------------------*/
#include "main.h"
#include "stm32f4xx.h" // For NVIC_SystemReset

/* USER CODE BEGIN Includes */
#include <math.h>
#include <string.h>
#include <stdlib.h>
#define ARM_MATH_CM4
#include "arm_math.h"
/* USER CODE END Includes */

/* USER CODE BEGIN PTD */
#define MAX_FRETS_SEQUENCE_LENGTH 500


// Motor driver control signals
typedef struct {
	uint8_t dir;       // Direction signal (0 = one direction, 1 = opposite)
	uint8_t enable;    // Motor enable state (0 = disabled, 1 = enabled)
	uint16_t step;     // Remaining steps to move
} controller_instance;

// Current kinematic state of the system
typedef struct {
	float position;    // Current position [mm]
	float velocity;    // Current velocity [mm/s]
	float acceleration;// Current acceleration [mm/s²]
} kinematic_instance;

// Timer configuration values
typedef struct {
	uint16_t arr;      // Auto-Reload Register value
	uint16_t psc;      // Prescaler value
} TimerValues;

// Solenoid control and state
typedef struct {
	uint8_t press_type;               // Type of pressing action (1: soft, 2: hard)
	uint8_t release_type;             // Type of release action (1: soft, 2: hard)
	uint8_t state;                    // 0: Disabled, 1: Active
	uint32_t hold_ticks;              // Number of ticks to hold the solenoid
	uint32_t time_accumulator_ticks;  // Accumulated time in ticks
	uint32_t start_count;             // Tick count when action started
	float duty;                       // PWM duty cycle for solenoid
	uint16_t arr;                     // ARR value associated with PWM
} solenoid_t;

// Structure for representing a song sequence
typedef struct {
	uint16_t bpm;                             			// Beats per minute
	uint8_t subdivision;                      			// Subdivision per beat
	uint8_t frets_sequence[MAX_FRETS_SEQUENCE_LENGTH]; // Frets stored as integers
	uint16_t index;                           			// Next free position to write
} Song;


/* USER CODE END PTD */

/* USER CODE BEGIN PD */
// System clock frequency
#define F_CPU 100000000 // Hz

// Diameter of the pulley attached to the motor shaft
#define PULLEY_DIAMETER 13.3 // mm

// Number of motor steps per full revolution (without microstepping)
#define STEPS_PER_REVOLUTION 200 // steps

// Maximum linear velocity allowed
#define MAX_VELOCITY 550.0 // mm/s

// Maximum linear acceleration allowed
#define MAX_ACCELERATION 5000.0 // mm/s²

// Maximum travel distance from the home position
#define MAX_POSITION 255.0 // mm

// Number of microsteps per full step
#define MICROSTEPS 32

// Number of motor steps per millimeter of linear movement
#define STEPS_PER_MM (STEPS_PER_REVOLUTION / (M_PI * PULLEY_DIAMETER))

// Total number of motor steps to reach maximum position
#define TOTAL_STEPS ((uint16_t)(MAX_POSITION * STEPS_PER_MM))

// Number of frets on the virtual guitar neck
#define NUM_FRETS 22

#define SAMPLING_FREQ_HZ 8000U
#define ADC_BUFFER_SIZE  8192

/* USER CODE END PD */

ADC_HandleTypeDef hadc1;
DMA_HandleTypeDef hdma_adc1;

TIM_HandleTypeDef htim1;
TIM_HandleTypeDef htim2;
TIM_HandleTypeDef htim3;
TIM_HandleTypeDef htim4;
TIM_HandleTypeDef htim5;

UART_HandleTypeDef huart2;
DMA_HandleTypeDef hdma_usart2_tx;

/* USER CODE BEGIN PV */
kinematic_instance kinematic = {0, 0, 0};    // Current kinematic state (position, velocity, acceleration)
controller_instance controller = {0, 0, 0};  // Motor control signals (dir, enable, steps)
solenoid_t solenoid = {0};                   // Solenoid control and state
Song current_song = {0};                     // Currently loaded song sequence
uint8_t micro_steps = 32;                    // Number of microsteps per full step
float homing_speed = MAX_VELOCITY * 0.5;      // Homing speed set to 50% of max velocity
volatile uint8_t solenoid_action_done_flag = 0; // Indicates if solenoid PWM action has completed

uint8_t status = 0; // System state machine
/*
   status = 0 -> Not calibrated
   status = 1 -> Motor enabled
   status = 2 -> Homing in progress
   status = 3 -> Position referenced (ready)
   status = 4 -> Moving to target position
 */

uint8_t playMode = 1; // Guitar neck mode
/*
   playMode = 0 -> String not tuned
   playMode = 1 -> Discrete guitar neck (virtual frets)
   playMode = 2 -> Continuous guitar neck (fretless)
 */
uint8_t servoAngle = 0; // Current servo angle

// UART VARIABLES
// Receiving buffers
uint8_t temp[20];          // Temporary buffer for incoming bytes
uint8_t command[10000];    // Buffer for assembling user commands
int ind_Com = 0;            // Index for command buffer
volatile int target_position = 0; // Desired motor target position

// Variables for controlling song playback
uint16_t arr_array[TOTAL_STEPS];  // Precomputed ARR values for each step
uint16_t psc_array[TOTAL_STEPS];  // Precomputed PSC values for each step
float desired_velocity = 0;       // Velocity to reach during song playback

int note_time_passed = 1;   // Flag to track note duration timeout
int is_playing = 0;       // 1 if a song is being played
int is_tunning = 0;       // 1 if tuning mode is active

// Guitar-related measurements
float string_length = 440.0f;  // String total length [mm]
float fret_positions[NUM_FRETS] = {0}; // Calculated fret positions along the string

// --- Predefined songs ---
// Example songs (replace or add as needed)
Song predefined_songs[] = {
    // Happy Birthday
    {
        .bpm = 80,
        .subdivision = 2,
        .frets_sequence = {0, 0, 2, 0, 5, 4, 100,100, 0, 0, 2, 0, 7, 5, 100,100,0,0,12,9,5,4,2,100,100,10,10,9,5,7,5,100,100},
        .index = 32
    },
    // Smoke on the Water
    {
        .bpm = 100,
        .subdivision = 2,
        .frets_sequence = {0,100, 3,100, 5,100,100, 0,100, 3,100, 6, 5,100,100,0,100, 3,100, 5,100,100, 3,100,0,100,100},
        .index = 27
    },
    // Come As You Are
    {
        .bpm = 110,
        .subdivision = 2,
        .frets_sequence = {0, 0, 1, 2,100, 5, 2, 5, 2, 2, 1, 0, 7, 0, 0, 100,7,0,1,2,5,2,5,2,2,1,0,7,0,0,100},
        .index = 32
    },
    // TEST
    {
        .bpm = 90,
        .subdivision = 2,
        .frets_sequence = {1, 0, 1, 2, 3, 0,0,0,0, 1,0,0,0,0,0,5, 0, 1, 0, 7, 0, 1,0,100,100,0,7,0,100,0,1},
        .index = 31
    }
};
#define NUM_PREDEFINED_SONGS (sizeof(predefined_songs)/sizeof(predefined_songs[0]))

volatile uint32_t tim5_overflow_count = 0; // Counter for TIM5 overflows (for timing)

uint16_t adc_buffer[ADC_BUFFER_SIZE];
float32_t fft_input[ADC_BUFFER_SIZE / 2];
float32_t fft_output[ADC_BUFFER_SIZE / 2];
arm_rfft_fast_instance_f32 fft_instance;

float32_t frequency;

// Agregar variable global para control de envío de frecuencia
volatile uint8_t send_frequency = 0;

/* USER CODE END PV */

void SystemClock_Config(void);
static void MX_GPIO_Init(void);
static void MX_DMA_Init(void);
static void MX_USART2_UART_Init(void);
static void MX_TIM1_Init(void);
static void MX_TIM2_Init(void);
static void MX_TIM4_Init(void);
static void MX_TIM5_Init(void);
static void MX_ADC1_Init(void);
static void MX_TIM3_Init(void);
/* USER CODE BEGIN PFP */
float calculate_velocity(float frequency);
float get_timer1_frequency();
float get_current_velocity();
float calculate_required_frequency(float velocity);


float calculate_position(float steps);
float calculate_acceleration(float initial_velocity, float final_velocity, float time);
int find_next_real_fret(uint8_t* sequence, uint16_t length, uint16_t start_index);


TimerValues calculate_arr_psc(float velocity);
void calculate_steps_speed(float target_position, uint16_t* arr_array);
void calculate_fret_positions();
void toggle_solenoid();
void play_song();
void play_note();
void homing();
void tuning();
void interpret_command();
void set_servo_position(uint8_t angle);
void configure_timer1_for_velocity(float velocity);
void process_half_buffer(const uint16_t *src);
float32_t calculate_frequency(const float32_t *samples, uint32_t fft_size, float32_t sample_rate);

/* USER CODE END PFP */

/**
  * @brief  The application entry point.
  * @retval int
  */
int main(void)
{

  /* MCU Configuration--------------------------------------------------------*/

  /* Reset of all peripherals, Initializes the Flash interface and the Systick. */
  HAL_Init();

  /* Configure the system clock */
  SystemClock_Config();

  /* Initialize all configured peripherals */
  MX_GPIO_Init();
  MX_DMA_Init();
  MX_USART2_UART_Init();
  MX_TIM1_Init();
  MX_TIM2_Init();
  MX_TIM4_Init();
  MX_TIM5_Init();
  MX_ADC1_Init();
  MX_TIM3_Init();
  /* USER CODE BEGIN 2 */

	HAL_UART_Receive_IT(&huart2, temp, 1);
	HAL_TIM_PWM_Start(&htim4, TIM_CHANNEL_1);
	calculate_fret_positions();

	// habilitar el reloj del timer:
	__HAL_RCC_TIM3_CLK_ENABLE();
	// habilitar el reloj del ADC:
	__HAL_RCC_ADC1_CLK_ENABLE();
	// habilitar el reloj del DMA:
	__HAL_RCC_DMA2_CLK_ENABLE();

	HAL_ADC_Start_DMA(&hadc1, (uint32_t*)adc_buffer, ADC_BUFFER_SIZE);
  /* USER CODE END 2 */

  /* Infinite loop */
  /* USER CODE BEGIN WHILE */
	arm_rfft_fast_init_f32(&fft_instance, ADC_BUFFER_SIZE/2);

	while (1)
	{
		if (is_playing == 1){
			play_song();
		}
		if (is_tunning == 1) {
			tuning();
		}

    /* USER CODE END WHILE */

    /* USER CODE BEGIN 3 */
	}
  /* USER CODE END 3 */
}

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
/* USER CODE BEGIN 4 */

volatile float current_velocity = 0; // Latest calculated linear velocity [mm/s]

/**
 * @brief Calculate linear velocity based on the timer output frequency.
 * @param frequency Output frequency of the timer [Hz]
 * @return Calculated linear velocity [mm/s]
 */
float calculate_velocity(float frequency) {
	float circumference = M_PI * PULLEY_DIAMETER; // Pulley circumference [mm]
	float velocity = (frequency * circumference) / (STEPS_PER_REVOLUTION * MICROSTEPS); // Linear velocity
	current_velocity = velocity; // Update global velocity
	return velocity;
}

/**
 * @brief Get the actual output frequency of Timer 1.
 * @return Timer 1 output frequency [Hz]
 */
float get_timer1_frequency() {
	uint32_t timer_clock = HAL_RCC_GetPCLK2Freq(); // Retrieve the peripheral clock frequency for Timer 1
	uint32_t prescaler = htim1.Init.Prescaler + 1; // Effective prescaler value
	uint32_t period = htim1.Init.Period + 1;       // Effective ARR value
	float frequency = (float)timer_clock / (prescaler * period);
	return frequency;
}

/**
 * @brief Get the current linear velocity of the system.
 * @return Current linear velocity [mm/s]
 */
float get_current_velocity() {
	float frequency = get_timer1_frequency(); // Measure current timer frequency
	return calculate_velocity(frequency);     // Convert to linear velocity
}

/**
 * @brief Calculate ARR and PSC values for a given linear velocity.
 * @param velocity Desired linear velocity [mm/s]
 * @return TimerValues structure with ARR and PSC values
 */
TimerValues calculate_arr_psc(float velocity) {
	float radius = PULLEY_DIAMETER / 2.0;                          // Radius of pulley [mm]
	float angular_velocity = velocity / radius;                   // Angular velocity [rad/s]
	float frequency = (angular_velocity * STEPS_PER_REVOLUTION) / (2 * M_PI); // Motor step frequency [steps/s]

	uint32_t tentative_arr = (uint32_t)(F_CPU / frequency) - 1;    // Initial ARR value
	uint16_t psc = 0;                                              // Initial prescaler

	// Adjust prescaler if ARR exceeds 16-bit timer limit
	if (tentative_arr > 0xFFFF) {
		psc = (tentative_arr / 0xFFFF) + 1;
		tentative_arr = (uint32_t)(F_CPU / ((psc + 1) * frequency)) - 1;
	}

	TimerValues values;
	values.arr = (uint16_t)tentative_arr;
	values.psc = psc;
	return values;
}

/**
 * @brief Set the desired linear velocity and configure system tick.
 * @param velocity Desired linear velocity [mm/s]
 */
void set_velocity(float velocity) {
	if (velocity < 0 || velocity > MAX_VELOCITY) {
		// Ignore invalid velocity values
		return;
	}

	desired_velocity = velocity; // Update desired velocity

	// Configure SysTick timer to trigger every 1 ms
	HAL_SYSTICK_Config(HAL_RCC_GetHCLKFreq() / 1000);
}

/**
 * @brief Configure Timer 1 to generate PWM corresponding to the desired velocity.
 * @param velocity Desired linear velocity [mm/s]
 */
void configure_timer1_for_velocity(float velocity) {
	if (velocity < 0 || velocity > MAX_VELOCITY) {
		// Ignore invalid velocity values
		return;
	}

	TimerValues values = calculate_arr_psc(velocity);

	// Update Timer 1 settings
	htim1.Init.Prescaler = values.psc;
	htim1.Init.Period = values.arr;
	htim1.Instance->CCR1 = values.arr / 2; // Set 50% duty cycle

	// Reinitialize Timer 1
	if (HAL_TIM_Base_Init(&htim1) != HAL_OK) {
		Error_Handler();
	}

	// Start Timer 1
	if (HAL_TIM_Base_Start(&htim1) != HAL_OK) {
		Error_Handler();
	}
}


/**
 * @brief Calculate linear position [mm] from number of motor steps.
 * @param steps Number of motor steps
 * @return Position in millimeters
 */
float calculate_position(float steps) {
	float circumference = M_PI * PULLEY_DIAMETER; // Pulley circumference [mm]
	float position = (steps * circumference) / STEPS_PER_REVOLUTION;
	return position;
}

/**
 * @brief Calculate linear acceleration given initial and final velocities over time.
 * @param initial_velocity Initial velocity [mm/s]
 * @param final_velocity Final velocity [mm/s]
 * @param time Time interval [s]
 * @return Acceleration [mm/s²]
 */
float calculate_acceleration(float initial_velocity, float final_velocity, float time) {
	float acceleration = (final_velocity - initial_velocity) / time;
	return acceleration;
}

/**
 * @brief Precompute timer ARR and PSC values to perform a motion to a target position
 *        with a trapezoidal velocity profile.
 * @param target_position1 Target position in millimeters
 * @param arr_array Output array to store ARR values step by step
 */
void calculate_steps_speed(float target_position1, uint16_t* arr_array) {
	if (target_position1 < 0 || target_position1 > MAX_POSITION) {
		return; // Ignore invalid target positions
	}
	target_position = target_position1;
	float distance;

	// Determine movement direction and set motor DIR pin
	if (kinematic.position < target_position) {
		distance = target_position - kinematic.position;
		controller.dir = 1; // Forward
		HAL_GPIO_WritePin(DIR_GPIO_Port, DIR_Pin, GPIO_PIN_SET);
	} else {
		distance = kinematic.position - target_position;
		controller.dir = 0; // Reverse
		HAL_GPIO_WritePin(DIR_GPIO_Port, DIR_Pin, GPIO_PIN_RESET);
	}

	float steps_per_mm = STEPS_PER_MM;
	uint16_t total_steps = (uint16_t)(distance * steps_per_mm);

	// Save total steps to move
	controller.step = total_steps;

	// Compute time and distance to accelerate to max speed
	float acceleration_time = (float)MAX_VELOCITY / (float)MAX_ACCELERATION;
	float acceleration_distance = 0.5f * (float)MAX_ACCELERATION * powf(acceleration_time, 2);

	// Calculate cruising distance (distance traveled at max speed)
	float cruise_distance = distance - 2 * acceleration_distance;
	if (cruise_distance < 0) {
		// No cruising phase, triangular profile (only acceleration and deceleration)
		acceleration_distance = distance / 2;
		cruise_distance = 0;
	}

	float cruise_time = cruise_distance / MAX_VELOCITY;

	// Calculate total motion time
	float total_time = 2 * acceleration_time + cruise_time;

	// Reset kinematic state
	kinematic.velocity = 0;
	kinematic.acceleration = MAX_ACCELERATION;

	// Precompute timer values for each step
	for (uint16_t step = 0; step < total_steps; step++) {
		float t = (float)step / (float)total_steps * total_time;

		if (t < acceleration_time) {
			// Acceleration phase
			kinematic.velocity = (float)MAX_ACCELERATION * t;
		} else if (t < acceleration_time + cruise_time) {
			// Constant velocity phase
			kinematic.velocity = MAX_VELOCITY;
		} else {
			// Deceleration phase
			kinematic.velocity = MAX_VELOCITY - MAX_ACCELERATION * (t - acceleration_time - cruise_time);
		}

		// Calculate ARR/PSC values for the current velocity
		TimerValues values = calculate_arr_psc(kinematic.velocity * MICROSTEPS);
		arr_array[step] = values.arr;
		psc_array[step] = values.psc;
	}

	// Configure timer for the first step immediately
	TIM1->ARR = arr_array[0];
	TIM1->PSC = psc_array[0];
	TIM1->CCR1 = arr_array[0] / 2; // 50% duty cycle
}


/**
 * @brief Toggle the solenoid state (ON/OFF).
 *        If the solenoid is off, it turns it on; if it's on, it turns it off.
 */
void toggle_solenoid() {
	if (solenoid.state == 0) {
		// Solenoid is off, turn it on
		HAL_GPIO_WritePin(SOL_GPIO_Port, SOL_Pin, GPIO_PIN_SET);
		solenoid.state = 1;
	} else {
		// Solenoid is on, turn it off
		HAL_GPIO_WritePin(SOL_GPIO_Port, SOL_Pin, GPIO_PIN_RESET);
		solenoid.state = 0;
	}
}

/**
 * @brief Calculate fret positions based on the string length and musical scale.
 *        Positions are adjusted by a mechanical offset based on the cart size.
 */
void calculate_fret_positions() {
	float offset = 17.2f; // Offset corresponding to half the solenoid carriage length [mm]

	for (int i = 0; i < (sizeof(fret_positions) / sizeof(fret_positions[0])); i++) {
		// Calculate raw position for each fret based on 12-TET (Twelve-tone equal temperament)
		float raw_position = string_length * (1.0f - 1.0f / powf(2.0f, i / 12.0f));

		// Apply mechanical offset
		fret_positions[i] = raw_position - offset;

		// Clamp position to 0 if it becomes negative
		if (fret_positions[i] < 0.0f) {
			fret_positions[i] = 0.0f;
		}
	}
}

// UART FUNCTIONS

/**
 * @brief Transmit a null-terminated string over UART2.
 * @param str Pointer to the string to transmit
 */
void send_string(char *str)
{
	int len = strlen(str); // Calculate the length of the string
	HAL_UART_Transmit_DMA(&huart2, (uint8_t*)str, len);
}

/**
 * @brief UART receive complete interrupt callback.
 *        Handles command parsing from user input.
 */
void HAL_UART_RxCpltCallback(UART_HandleTypeDef *huart) {
	if (huart->Instance == USART2) {
		char received_char = temp[0]; // Capture the received character

		// Handle special characters
		if (received_char == ':') {
			// Start of a new command: clear the command buffer
			ind_Com = 0;
			memset(command, 0, sizeof(command));
		}
		else if (received_char == 0x08 || received_char == 0x7F) {
			// Backspace or delete: remove last character from buffer
			if (ind_Com > 0) {
				ind_Com--;
				command[ind_Com] = '\0';
			}
		}
		else if (received_char == '\n' || received_char == '\r') {
			// Enter key pressed: finalize and process the command
			if (ind_Com > 0) {  // Solo procesar si hay caracteres en el buffer
				command[ind_Com] = '\0';  // Asegurar que el comando termine en null
				interpret_command(); // Interpret and execute the received command
				ind_Com = 0;
				memset(command, 0, sizeof(command));
			}
		}
		else if (ind_Com < sizeof(command) - 1) {
			// Regular printable character: store it
			command[ind_Com++] = received_char;
		}

		// Reactivate UART reception for next character
		HAL_UART_Receive_IT(&huart2, temp, 1);
	}
}


/**
 * @brief Timer period elapsed callback.
 *        Handles actions depending on which timer triggered the interrupt.
 */
void HAL_TIM_PeriodElapsedCallback(TIM_HandleTypeDef *htim) {
	static uint8_t accumulator = 0; // Accumulator for microstepping

	if (htim->Instance == TIM1) {
		// Timer 1: Motor motion control
		switch (status) {
		case 2: // Homing operation in progress
			// No action needed, waiting for external event (limit switch)
			break;

		case 4: // Normal movement to a target position
			if (controller.step > 0) {
				// Decrement step counter only after completing a microstep batch
				if (accumulator++ >= MICROSTEPS) {
					accumulator = 0;
					controller.step--;

					// Update timer parameters for new velocity
					TIM1->ARR = arr_array[controller.step];
					TIM1->PSC = psc_array[controller.step];
					TIM1->CCR1 = arr_array[controller.step] / 2; // 50% duty cycle
				}
			} else {
				// All steps completed: stop PWM and update system status
				HAL_TIM_PWM_Stop(&htim1, TIM_CHANNEL_1);
				status = 3; // Now "position referenced"

				// If motor is still enabled, update kinematic position
				if (HAL_GPIO_ReadPin(ENA_GPIO_Port, ENA_Pin) == GPIO_PIN_RESET) {
					kinematic.position = target_position;
				}
			}
			break;

		default:
			break;
		}
	}

	else if (htim->Instance == TIM2) {
		// Timer 2: Used to track note duration during song playback
		note_time_passed = 1;
		HAL_TIM_Base_Stop_IT(&htim2); // Stop the timer after timeout
	}

	else if (htim->Instance == TIM5) {
		// Timer 5: Overflow counter for high precision delays
		tim5_overflow_count++;
	}
}
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

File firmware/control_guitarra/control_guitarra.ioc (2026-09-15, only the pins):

Mcu.UserName=STM32F411RETx
PA0-WKUP.Signal=ADCx_IN0
PA13.GPIO_Label=TMS
PA13.Signal=SYS_JTMS-SWDIO
PA14.GPIO_Label=TCK
PA14.Signal=SYS_JTCK-SWCLK
PA2.GPIO_Label=USART_TX
PA2.Signal=USART2_TX
PA3.GPIO_Label=USART_RX
PA3.Signal=USART2_RX
PA5.GPIO_Label=LD2 [Green Led]
PA5.Signal=GPIO_Output
PA8.GPIO_Label=STEP
PA8.Signal=S_TIM1_CH1
PA9.GPIO_Label=DIR
PA9.Signal=GPIO_Output
PB3.GPIO_Label=SWO
PB3.Signal=SYS_JTDO-SWO
PB6.GPIO_Label=SERVO
PB6.Signal=S_TIM4_CH1
PC13-ANTI_TAMP.GPIO_Label=B1 [Blue PushButton]
PC13-ANTI_TAMP.Signal=GPXTI13
PC14-OSC32_IN.Signal=RCC_OSC32_IN
PC15-OSC32_OUT.Signal=RCC_OSC32_OUT
PC7.GPIO_Label=ENA
PC7.Signal=GPIO_Output
PC8.GPIO_Label=SOL
PC8.Signal=GPIO_Output
PC9.GPIO_Label=FC
PC9.Signal=GPXTI9

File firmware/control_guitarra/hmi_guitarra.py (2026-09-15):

import curses
import serial
import threading
import time
import re
import math

# Notas y frecuencias base (A4 = 440 Hz)
NOTE_NAMES = ['C', 'C#', 'D', 'D#', 'E', 'F', 'F#', 'G', 'G#', 'A', 'A#', 'B']
A4_INDEX = NOTE_NAMES.index('A') + 12 * 4  # MIDI index for A4

# Calcular frecuencia de cualquier nota/octava
def note_freq(note, octave):
    n = NOTE_NAMES.index(note) + 12 * (octave)
    return 440.0 * (2 ** ((n - A4_INDEX) / 12))

def get_next_frets(note, octave, num_frets=12):
    idx = NOTE_NAMES.index(note) + 12 * octave
    frets = []
    for i in range(num_frets+1):
        nidx = idx + i
        nname = NOTE_NAMES[nidx % 12]
        noct = nidx // 12
        frets.append(f"{i}: {nname}{noct}")
    return frets

# Diccionario de errores y estados
ERROR_CODES = {
    'X1': 'Valeur invalide dans la séquence',
    'X2': 'Frette hors plage',
    'X3': 'Format BPM invalide',
    'X4': 'Valeurs BPM invalides',
    'X5': 'Format de frette invalide',
    'X6': 'Séquence de frettes pleine',
    'X7': 'Combinaison de frettes invalide',
    'X8': 'Homing non effectué',
    'X9': 'Aucune chanson chargée',
    'X10': 'Aucun BPM',
    'X11': 'Le chargement de la chanson nécessite un homing',
    'X12': 'Numéro de chanson invalide',
}
STATE_CODES = {
    'EN': 'Moteur activé',
    'ED': 'Moteur désactivé',
    'N': 'Note jouée',
    'A': 'Mode accordage activé',
    'AR': 'Mode accordage désactivé',
    'G': 'Lecture de la chanson commencée',
    'GR': 'Lecture de la chanson terminée',
    'C': 'Chanson chargée',
    'T': 'Frette ajoutée',
}

SONG_TITLES = [
    "Joyeux Anniversaire (exemple)",
    "Smoke on the Water (exemple)",
    "Come As You Are (exemple)",
    "Chanson Test (exemple)"
]

# Información de afinación para cada canción (nota, octava)
SONG_TUNING = [
    ("E", 4),  # Joyeux Anniversaire
    ("E", 4),  # Smoke on the Water
    ("E", 4),  # Come As You Are
    ("E", 4)   # Chanson Test
]

SELECTED_SONG_IDX = 0
SELECTED_SONG_NAME = SONG_TITLES[0]

class SerialReader(threading.Thread):
    def __init__(self, ser):
        super().__init__()
        self.ser = ser
        self.freq = None
        self.last_code = None
        self.running = True
        self.lock = threading.Lock()
    def run(self):
        freq_pattern = re.compile(r"^\s*:F([0-9.]+)")
        code_pattern = re.compile(r":([A-Z]+[0-9]*)")
        while self.running:
            try:
                line = self.ser.readline().decode(errors='ignore').strip()
                m = freq_pattern.search(line)
                if m:
                    with self.lock:
                        self.freq = float(m.group(1))
                else:
                    m2 = code_pattern.search(line)
                    if m2:
                        with self.lock:
                            self.last_code = m2.group(1)
            except Exception:
                pass
    def get_freq(self):
        with self.lock:
            return self.freq
    def get_code(self):
        with self.lock:
            code = self.last_code
            self.last_code = None
            return code
    def stop(self):
        self.running = False

def safe_addstr(stdscr, y, x, string, *args):
    h, w = stdscr.getmaxyx()
    if 0 <= y < h and 0 <= x < w:
        # Coupe la chaîne si elle dépasse la largeur
        max_len = w - x
        stdscr.addstr(y, x, string[:max_len], *args)

def draw_menu(stdscr, selected, options, title, status_msg=None):
    stdscr.clear()
    h, w = stdscr.getmaxyx()
    safe_addstr(stdscr, 1, w//2 - len(title)//2, title, curses.A_BOLD)
    for idx, opt in enumerate(options):
        x = w//2 - len(opt)//2
        y = 3 + idx
        if idx == selected:
            stdscr.attron(curses.color_pair(1))
            safe_addstr(stdscr, y, x, opt)
            stdscr.attroff(curses.color_pair(1))
        else:
            safe_addstr(stdscr, y, x, opt)
    if status_msg:
        safe_addstr(stdscr, h-3, 2, status_msg, curses.A_BOLD)
    stdscr.refresh()

def draw_tuning(stdscr, note_idx, octave, freq_obj, ser, status_msg=None):
    stdscr.clear()
    h, w = stdscr.getmaxyx()
    note = NOTE_NAMES[note_idx]
    freq_target = note_freq(note, octave)
    safe_addstr(stdscr, 1, w//2 - 12, "Accordage de la corde", curses.A_BOLD)
    safe_addstr(stdscr, 3, 4, f"Note : [{note}]   Octave : [{octave}]   Fréq. cible : {freq_target:.2f} Hz")
    freq = freq_obj.get_freq()
    bar_y = 5
    bar_margin = 8
    bar_len = w - 2*bar_margin - 2
    if bar_len < 21:
        bar_len = 21
    center = bar_len // 2
    if freq is not None:
        diff = freq - freq_target
        visual_range = 200.0  # ±200 Hz
        norm = max(-1.0, min(1.0, diff / visual_range))
        pos = int(center + norm * (bar_len / 2))
        pos = max(0, min(bar_len-1, pos))
        bar = ['-'] * bar_len
        bar[center] = '+'
        bar[pos] = '|'
        bar_str = ''.join(bar)
        safe_addstr(stdscr, bar_y, bar_margin, bar_str)
        if abs(diff) <= 5:
            action = "Accordé !"
            color = curses.color_pair(2)
        elif diff < 0:
            action = "Tendre la corde"
            color = curses.color_pair(3)
        else:
            action = "Détendre la corde"
            color = curses.color_pair(4)
        freq_str = f"{freq:.2f} Hz"
        safe_addstr(stdscr, bar_y+1, w//2 - len(freq_str)//2, freq_str, color)
        safe_addstr(stdscr, bar_y+2, w//2 - len(action)//2, action, color)
    else:
        safe_addstr(stdscr, bar_y, bar_margin, "En attente de fréquence...")
    frets = get_next_frets(note, octave)
    safe_addstr(stdscr, bar_y+4, 4, "Frettes suivantes :")
    fret_line = ''
    row = bar_y+5
    for f in frets:
        fret_line += f + '   '
        if len(fret_line) > w-10:
            safe_addstr(stdscr, row, 4, fret_line)
            fret_line = ''
            row += 1
    if fret_line:
        if row < h:
            max_len = w - 8 if w > 8 else 0
            safe_addstr(stdscr, row, 4, fret_line[:max_len])
    safe_addstr(stdscr, h-2, 4, "← → note, ↑ ↓ octave, Q pour revenir")
    if status_msg:
        safe_addstr(stdscr, h-3, 4, status_msg, curses.A_BOLD)
    stdscr.refresh()

def draw_progress_bar(stdscr, progress, label="Homing en cours..."):
    h, w = stdscr.getmaxyx()
    bar_len = w - 20
    filled = int(bar_len * progress)
    bar = '[' + '='*filled + ' '*(bar_len-filled) + ']'
    stdscr.clear()
    safe_addstr(stdscr, h//2-1, w//2 - len(label)//2, label, curses.A_BOLD)
    safe_addstr(stdscr, h//2, w//2 - bar_len//2, bar)
    stdscr.refresh()

def send_serial_slow(ser, data, delay=0.01):
    """Envía una cadena por serial, byte a byte, con un pequeño delay entre cada byte."""
    if isinstance(data, str):
        data = data.encode()
    for b in data:
        ser.write(bytes([b]))
        ser.flush()
        time.sleep(delay)
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

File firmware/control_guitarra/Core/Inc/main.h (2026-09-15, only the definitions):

#define B1_Pin GPIO_PIN_13
#define B1_GPIO_Port GPIOC
#define B1_EXTI_IRQn EXTI15_10_IRQn
#define USART_TX_Pin GPIO_PIN_2
#define USART_TX_GPIO_Port GPIOA
#define USART_RX_Pin GPIO_PIN_3
#define USART_RX_GPIO_Port GPIOA
#define LD2_Pin GPIO_PIN_5
#define LD2_GPIO_Port GPIOA
#define ENA_Pin GPIO_PIN_7
#define ENA_GPIO_Port GPIOC
#define SOL_Pin GPIO_PIN_8
#define SOL_GPIO_Port GPIOC
#define FC_Pin GPIO_PIN_9
#define FC_GPIO_Port GPIOC
#define FC_EXTI_IRQn EXTI9_5_IRQn
#define STEP_Pin GPIO_PIN_8
#define STEP_GPIO_Port GPIOA
#define DIR_Pin GPIO_PIN_9
#define DIR_GPIO_Port GPIOA
#define TMS_Pin GPIO_PIN_13
#define TMS_GPIO_Port GPIOA
#define TCK_Pin GPIO_PIN_14
#define TCK_GPIO_Port GPIOA
#define SWO_Pin GPIO_PIN_3
#define SWO_GPIO_Port GPIOB
#define SERVO_Pin GPIO_PIN_6
#define SERVO_GPIO_Port GPIOB

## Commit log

2026-09-15 Premier commit : import du projet et README de reprise
    Le projet est rangé dans vscode/trainning/projets et documenté pour être
    repris sans difficulté : contenu, relance, pistes d'amélioration.
    Vidéos, archives, fichiers générés et outils tiers restent hors du dépôt.
    [Assemblage varié.SLDASM, Assemblage1.SLDASM, BRAS MEDIATOR.SLDPRT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]
2026-09-15 Typographie du README : ni tiret cadratin, ni esperluette
    « A — B » devient « A : B », et les incises passent en virgules ou en
    parenthèses.
2026-09-20 Simulation rejouable, et une chaine qui compile le micrologiciel
    La simulation etait un dossier d'essais successifs, et le README renvoyait vers
    un fichier vide. Le modele cinematique devient le fichier de reference,
    animation_cinematique.py, utilisable sans fenetre ; produire-figures.py le
    rejoue et ecrit trois images : le bras en mouvement, le chemin de l'outil, et
    les courbes de vitesse et d'acceleration des deux axes.
    Une chaine d'integration compile le micrologiciel STM32 hors de CubeIDE, affiche
    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
2026-09-20 Chaine : installer newlib, qui apporte nano.specs
    Le paquet du compilateur ARM seul n'apporte pas les specifications de la
    bibliotheque reduite, et la compilation s'arretait au premier fichier.
2026-09-20 Le geste humain mesure, et les animations rendues lisibles
    Le releve Kinovea du geste du mediator dormait dans documents/ sous forme de
    fichier XML. Il est maintenant relu par un script : etalonnage sur l'ecart de
    onze millimetres entre deux cordes, conversion en millimetres et en secondes,
    puis les chiffres qui contraignent le mecanisme. Deux cent soixante-douze
    points suivis, 33 mm de balayage, 465 mm/s en pointe : c'est la cible que la
    simulation doit tenir.
    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
2026-09-25 Les figures de la simulation viennent du modèle du projet
    Le script produisait trois images tirées d'un modèle abrégé à deux corps, en
    unités abstraites : un bras d'un mètre vingt de balayage, des axes gradués en
    mètres, alors que le robot balaie trente-trois millimètres. Elles étaient
    publiées sur le portfolio et déposées par la chaîne comme si elles décrivaient
    le mécanisme.
    Il importe maintenant `essais/test python32.py`, le seul modèle qui fait foi,
    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

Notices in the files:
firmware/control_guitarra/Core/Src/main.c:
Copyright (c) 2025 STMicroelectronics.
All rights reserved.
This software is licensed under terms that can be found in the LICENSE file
